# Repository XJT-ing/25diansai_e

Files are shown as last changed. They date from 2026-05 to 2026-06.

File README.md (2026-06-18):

# 2025 National Undergraduate Electronics Design Contest - Problem E

This repository contains the source code, schematics, 3D models, system block diagram, and project report for our 2025 National Undergraduate Electronics Design Contest Problem E project.

Award: National Second Prize

## Project Overview

This project implements a simple automatic aiming device based on machine vision, embedded control, motor actuation, and closed-loop correction.

## Repository Structure

- `源码/`: source code for MaixCam Pro and microcontroller control
- `原理图/`: circuit schematics
- `3D建模/`: 3D models and mechanical structure files
- `总体框图.png`: overall system block diagram
- `报告.pdf`: project report

## Note

This repository is intended for learning, communication, and project demonstration only.

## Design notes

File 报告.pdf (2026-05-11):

装订 | 装订 | 装订

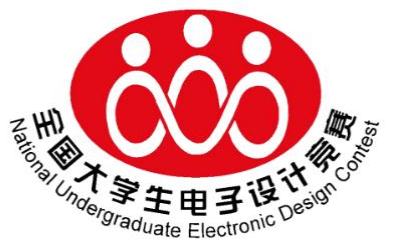
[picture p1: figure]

# 2025年全国大学生电子设计竞赛

## 简易自行瞄准装置（E题）

3cm | 参赛队代码：

装订 | 装订 | 装订

3cm

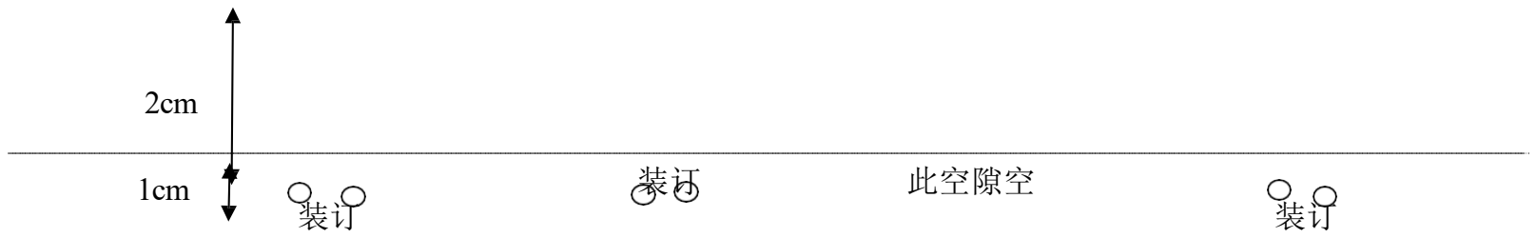
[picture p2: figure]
此空隙空

## 简易自行瞄准装置

摘要

本设计实现了集机械控制运动系统与视觉识别系统为一体的简易自行瞄准装

置。机械控制运动系统包含两部分：以 TI MSPM0G3507 为主控的自动循迹小车系

统，可按指令在规定时间沿正方形黑线精准循迹行驶设定圈数；以STM32F407VET6

为主控、步进电机驱动二维云台的激光瞄准模块，能依据接收数据完成打靶动作。

视觉识别系统基于 Sipeed MaixCAM Pro，可精准识别紫外感光靶面的轮廓、靶心

及红色圆圈，为瞄准模块提供实时定位。瞄准模块借助步进电机二维云台调控蓝

紫激光笔，无论小车静止或行驶，均可快速实现激光瞄准，保障光斑直径与距离

精度达标 。

关键词：简易自行瞄准装置；自动寻迹；激光瞄准；靶面视觉识别。

# 1.系统方案

## 1.1.机械运动控制系统方案选择

### 1.1.1. 主控选择

方案一：STM32F103C8T6。价格亲民、资料丰富易开发，但性能有限，串口数

量少，多任务处理易资源紧张。

方案二：TI MSPM0G3507。功耗低，运算高效，针对低功耗场景深度优化，

能稳定支撑自动循迹小车的基础控制需求 。

方案三：STM32F407VET6。运算性能强，具备丰富外设接口（如多路串口等），

能高效处理激光瞄准控制中的多信息交互，开发生态成熟，易于调试。

方案选择：本系统由自动循迹小车（需稳定运算主控）与激光瞄准模块（需

高性能及电机控制）构成。TIMSPM0G3507契合小车基础控制需求；STM32F407VET6

凭借高性能与丰富外设，满足瞄准模块多信息处理、精准控制要求。二者协同，

保障小车稳定、瞄准模块高效，故选用TI MSPM0G3507作为自动循迹小车主控，

STM32F407VET6作为激光瞄准模块主控 。

## 1.1.2. 机械运动部分选择

方案一：四轮四驱循迹小车，搭配舵机搭建二维云台。四驱动虽能提供较强

动力，但对于沿正方形轨迹寻迹场景，双驱动已可满足行驶需求。且四驱可能导

致转弯打滑，影响行驶稳定性；舵机虽响应较快，但在二维云台角度的精准控制，

较难满足精度要求。

方案二：四轮双驱循迹小车，搭配步进电机搭建二维云台。双驱设计简化驱

动结构，降低能耗与控制难度，更适配循迹场景的动力需求，能稳定沿黑色边线

行驶，确保小车投影不脱离轨迹；步进电机具备高精度角度控制能力，可精准驱

动二维云台调整蓝紫激光笔方向，满足静止或行驶时激光瞄准的精度要求，契合

靶面光斑直径及距离精度的指标。

方案选择：方案一存在结构冗余，易影响行驶稳定性与瞄准精度；方案二的

双驱设计适配循迹需求，步进电机驱动的云台能保障激光瞄准精度，符合装置核

心要求，故选择方案二作为系统的机械运动控制系统。

## 1.2.视觉识别系统方案选择

方案一：K210 视觉模块。主芯片为 K210，采用双核 64 位 RISC - V 架构，

算力达 1TOPS，集成 KPU 等硬件加速器，能实现靶面轮廓、靶心等基础特征识别。

不过在复杂光照或靶面有轻微形变等情况下，识别精度会受到影响，且算力拓展

空间相对有限。

方案 二 ： MaixCAM Pro 。 配 备 高 性 能 处 理 器 ， 拥 有 1GHz RISC - V

(C906)+700MHz RISC - V 的强劲 CPU 组合，搭配 256MB DDR3 内存，NPU 算力

出色，支持高分辨率图像采集，可精准识别靶面细微特征，如窄线宽的红色圆圈、

极小的靶心等 。开发环境资源丰富。

方案选择：K210 在复杂场景下的识别精度和算力方面存在局限，难以满足

本装置对靶面高精度识别的要求。而 MaixCAM Pro 凭借强大的性能、精准的识

别能力以及丰富的开发环境资源，更契合简易自行瞄准装置中视觉识别系统的核

心需求，因此选用方案二作为视觉识别系统。

## 1.3 总体方案描述

系统主要包括机械运动控制系统和视觉识别系统。其中，机械运动控制系统：

小车由TI MSPM0G3507和四轮双驱的循迹小车结构组成，激光瞄准模块由

STM32F407VET6和步进电机二维云台结构组成；视觉识别系统由MaixCAM Pro组成。

总体框如图 1-1 所示。

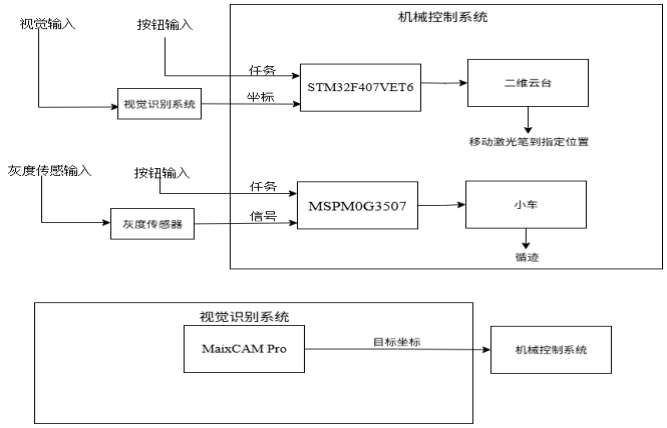
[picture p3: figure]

图 1-1 系统总体框图

# 2.理论分析与计算

## 2.1系统控制逻辑与核心算法

简易自行瞄准装置通过自动寻迹控制与瞄准调节控制协同工作，核心算法包

括灰度传感器寻迹算法、PID 控制算法及坐标映射算法。

自动寻迹小车以 TI MSPM0 系列 MCU 为控制核心，通过 8 路灰度传感器采集

轨迹信息，将传感器数据与预设黑白阈值对比，生成数字信号判断小车相对于黑

色轨迹的位置偏移1。基于偏移量，采用 PID 算法实时调节左右电机转速，实现

沿 100cm×100cm 正方形轨迹的逆时针自动寻迹，确保行驶圈数（1-5 圈）和时

间（≤20s）符合要求。

瞄准模块依托二维云台控制激光笔，采用坐标映射算法将靶面光斑与靶心的

偏差转换为云台角度调节量，结合 PID 算法实现快速瞄准：静态状态下 2s 内、

指定位置 4s 内使光斑距靶心≤2cm。

## 2.2代码实现思路

1.小车控制代码：初始化灰度传感器、电机及 PID 控制器后，进入循环采集

传感器数据，通过数字信号判断轨迹位置。利用编码器记录行驶距离，结合预设

圈数阈值触发停止逻辑，同时通过 OLED 显示行驶参数，确保行驶过程中投影不

脱离轨迹。

2.瞄准模块代码：通过串口接收靶面偏差数据，经校验后转换为目标角度。

初始化 x、y 轴 PID 控制器，根据偏差计算输出量，驱动二维云台调整激光方向。

在发挥部分，通过关联小车行驶距离与圆弧坐标，实现小车行驶 1 圈时激光沿

6cm 半径圆弧同步画圆，保证同步误差 < 1/4 圈。

3.协同控制：MSPM0 控制器与瞄准模块通过独立电源开关控制，行驶与瞄准过

程中，前者负责轨迹跟踪，后者根据位置动态调节激光方向，在发挥部分实现行

驶与瞄准的连续协同。

# 3.电路与程序设计

## 3.1 电路设计

本系统主要的电路设计分为为稳压电路部分、电机控制部分、以及系统底板

部分。

## 3.1.1 稳压电路部分

基于 RT8289GSP 芯片构建 5V 电源电路，搭配滤波、过温保护等元件；通过

RT9013 - 33GB 实现 5V 转 3.3V ，满足系统供电需求，电路如图所示。稳压电

路如图 3-1。

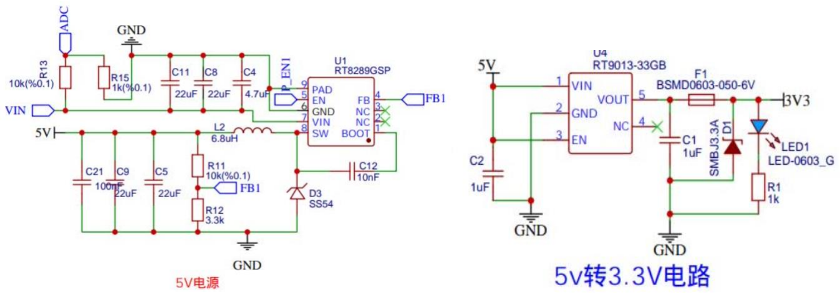
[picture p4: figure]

图 3-1 稳压电路

## 3.1.2 电机控制部分

为了驱动二维云台且满足较高的精度要求。我们使用了 2 台 42 步进电机及

其配套的驱动板。我们将三台电机的驱动排线接在电机转接板上，转接板上，两

个电机使用串口与主控f4进行通信。同时，主控TI MSPM0G3507利用TB6612FNG驱

动模块驱动小车电机。电机控制电路如图 3-2所示。

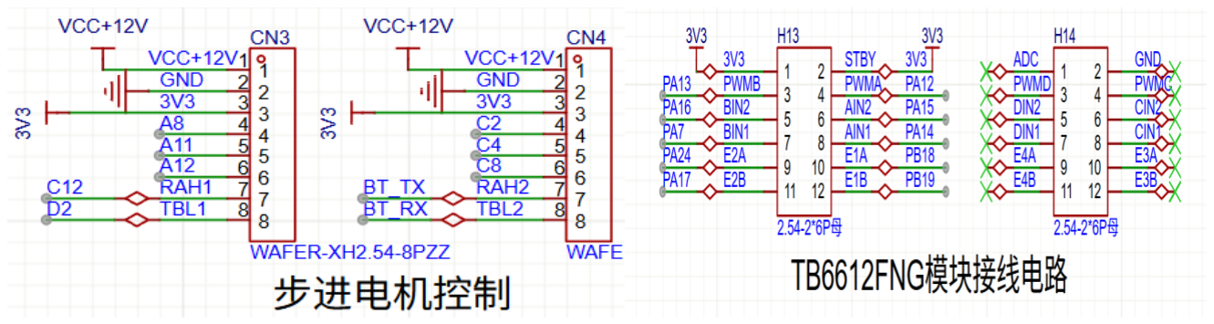
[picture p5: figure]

图 3-2 电机控制电路

## 3.1.3 系统底板部分

对于转接使用到的 IO 口，我们设计了一块底板，能够将TI MSPM0G3507核心

板和STM32F407VET6 核心板直接插入底板，排母将核心板上面的 IO 口引脚与电

机和电源连接，同时还将未使用的 IO 口引出供其他外设（如LED灯、IMU等）使

用。底板的原理图如图3-3所示。

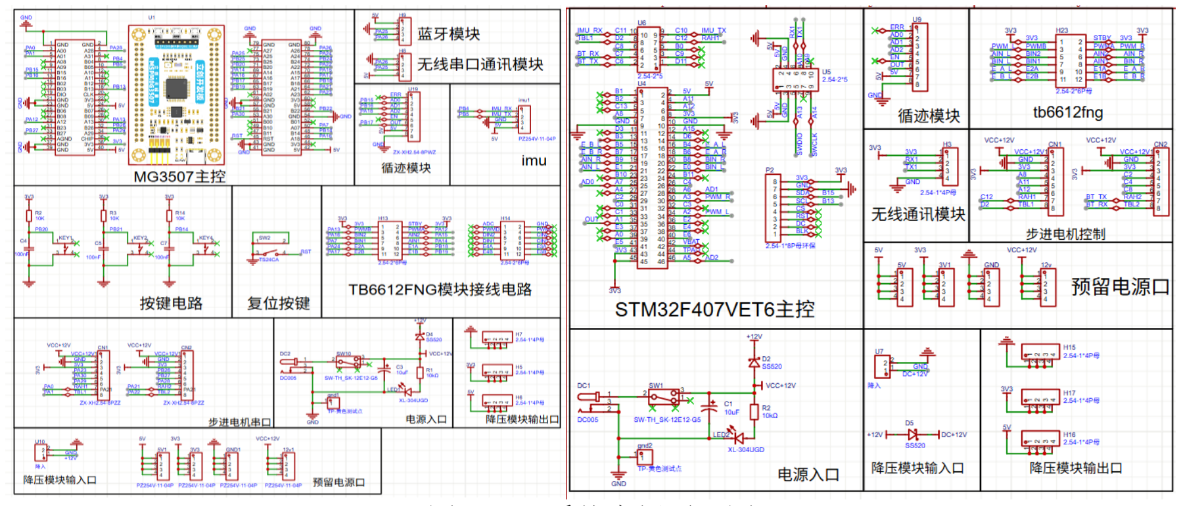
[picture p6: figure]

图 3-3 系统底板原理图

## 3.1 程序设计

本系统的程序设计主要分为机械运动控制系统部分和视觉识别系统部分。

## 3.1.1 机械运动控制系统：

本系统由TI MSPM0G3507和STM32F407VET6为主控，以 TI MSPM0G3507 为主控，

通过 TB6612FNG 输出 PWM 波控制小车电机，实现电机调速与转向控制。以

STM32F407VET6 为主控，使用串口对两个 42 步进电机进行控制，驱动支持串口

指令配置速度及转动距离。同时，系统通过按钮或者根据视觉控制系统所给的信

号对不同任务做出不同指令。

## 3.1.2 视觉识别系统

本设计以MaixCAM Pro为视觉识别系统的主控，进一步识别目标，加入IMU辅助

PID控制，将目标点与激光点差值通过串口发送到电机控制系统，使激光笔能够在

uav纸上打出想要的点和轨迹。

# 4.测试方案与测试结果

## 4.1.测试方案 4.1.1 地图及靶标的设计

地图设计：为满足小车自动寻迹需求，采用白色哑光喷绘布制作行驶场地，

水平铺于平地。按要求绘制 100cm×100cm 的正方形行驶轨迹，边线为黑色，线

宽控制在 1.8cm±0.2cm，与题目要求一致。

靶标设计：目标靶采用 A4 幅面紫外感光纸的感光面。在感光纸边缘，用

1.8cm 宽的黑色哑光胶布粘贴成长方形，勾勒出靶纸外轮廓；以靶心（直径

≤0.1cm）为圆心，用红色油性记号笔分别绘制半径为 2、4、6、8 和 10cm 的红

色圆，圆弧线宽度≤0.1cm，符合题目对靶面标记的要求，便于视觉识别系统定位

靶心及各圆弧位置。同时，靶标竖立在距离 AB 线段外 50cm 处，靶面与 AB 保

持平行，高度≤50cm，周围无强光干扰，保证激光照射后能清晰留下感光痕迹。

## 4.2 测试结果完整性

要求项 | 要求说明 | 完成情况 | 是否 达标
完成基本 要求（1） | 沿轨迹行驶，圈 数可设且限时。 | 行驶圈数 N 可在 1-5 之间设定，行驶时间 t≤20s | 是
完成基本 要求（2） | 自定位置 2s 内 瞄准靶心。 | 2s内完成且距离靶心小于2cm | 是
完成基本 要求（3） | 指定位置 4s 内 瞄准靶心。 | 4s内完成且距离靶心小于2cm | 是
完成发挥 部分（1） | 1 圈行驶，20s 内瞄准 | 绝大部分时间完成 | 基本 达标
完成发挥 部分（2） | 2 圈行驶，40s 内瞄准 | 50%概率完成 | 基本 合格

## 4.3 测试结果分析

本系统能良好完成部分要求，但测试次数较少，可能存在不稳定性，还存在

改进空间。

## 4.4 总结展望

本次设计旨在开发一种简易自行瞄准装置，使大家能够感受到机械运动控制

和视觉识别的魅力。在这此项目的制作中，我们团队学到了很多。首先，我们学

到了如何进行系统化的需求分析和设计规划。其次，我们学到了如何进行合理的

电路设计以及系统方案的选择。此外，我们团队还学到了团队合作和项目管理的

重要性。最终，我们的作品虽然与预期水平有差距，但已经是我们全力以赴，共

同协作努力的结果。

要求项 | 要求说明 | 完成情况 | 是否 达标
完成发挥 部分（3） | 1 圈行驶，同步 画指定圆 | 未完成 | 否
完成发挥 部分（其 他） | 其他创新性表现 | 可现场学习人脸并在识别人脸时 关闭激光笔保护人眼 | 是

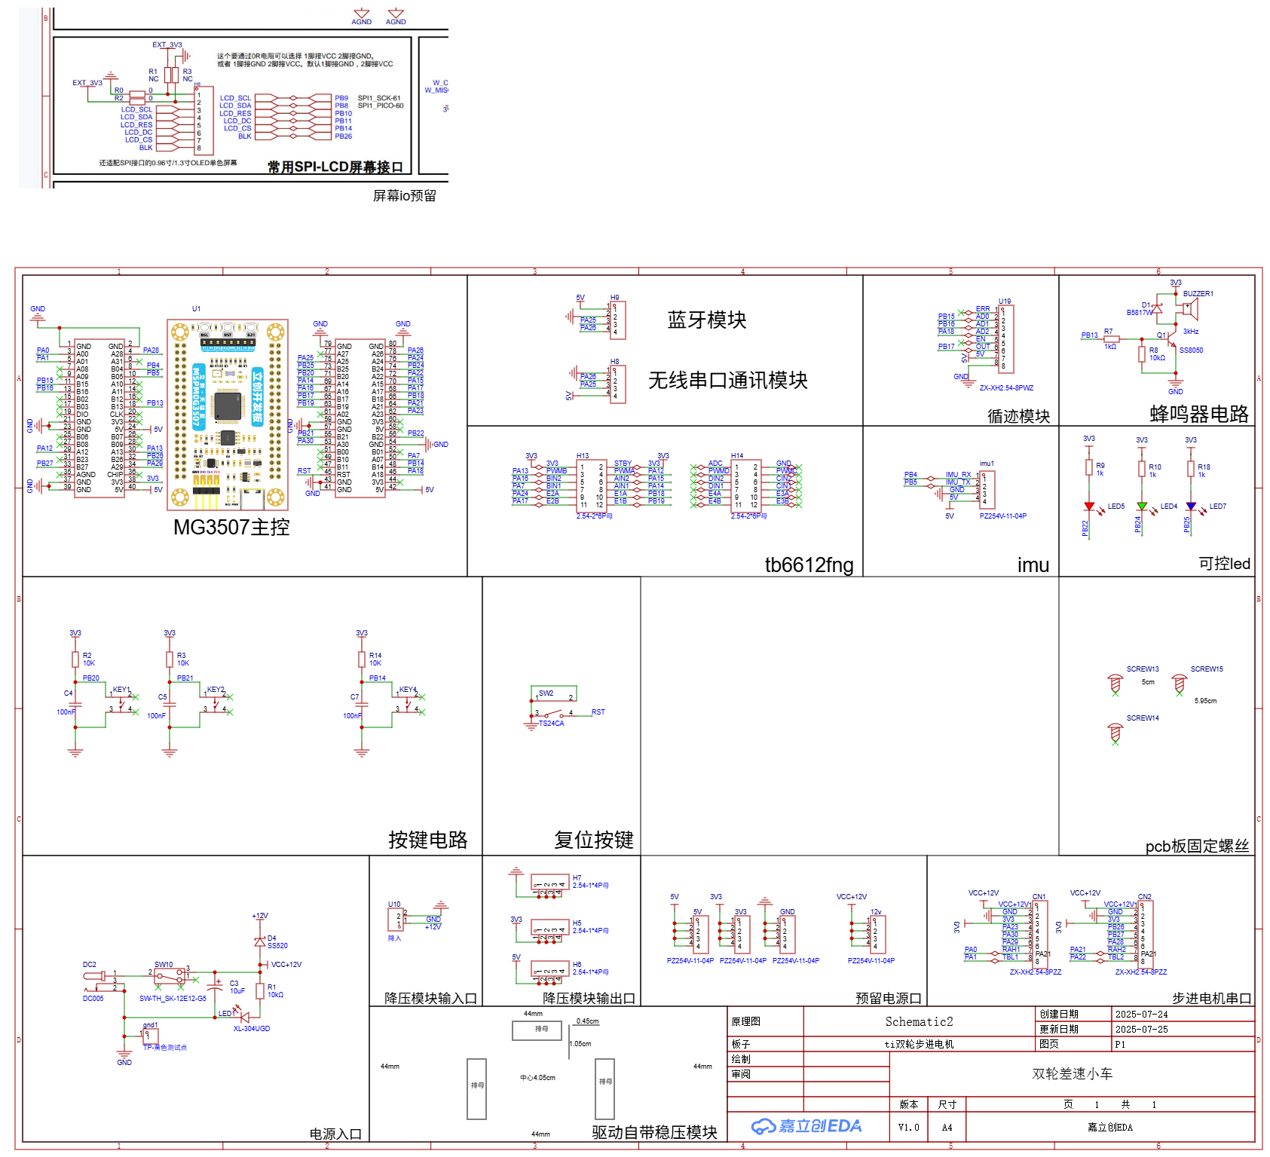
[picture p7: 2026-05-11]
原理图/SCH_Schematic2_1-P1_2025-08-01.png

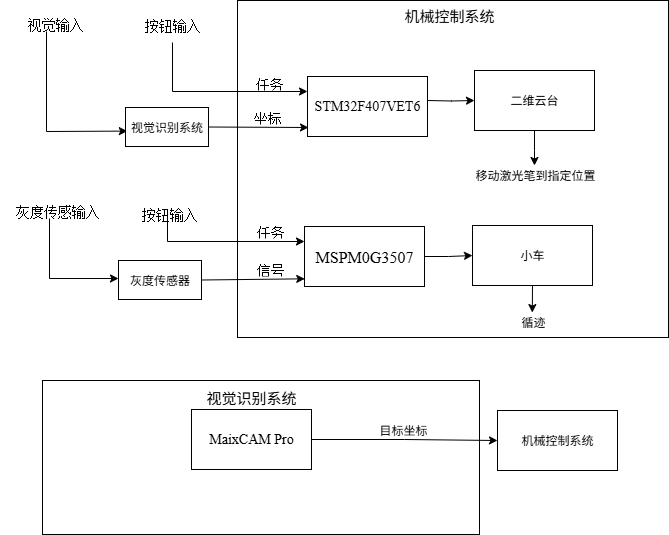
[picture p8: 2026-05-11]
总体框图.png

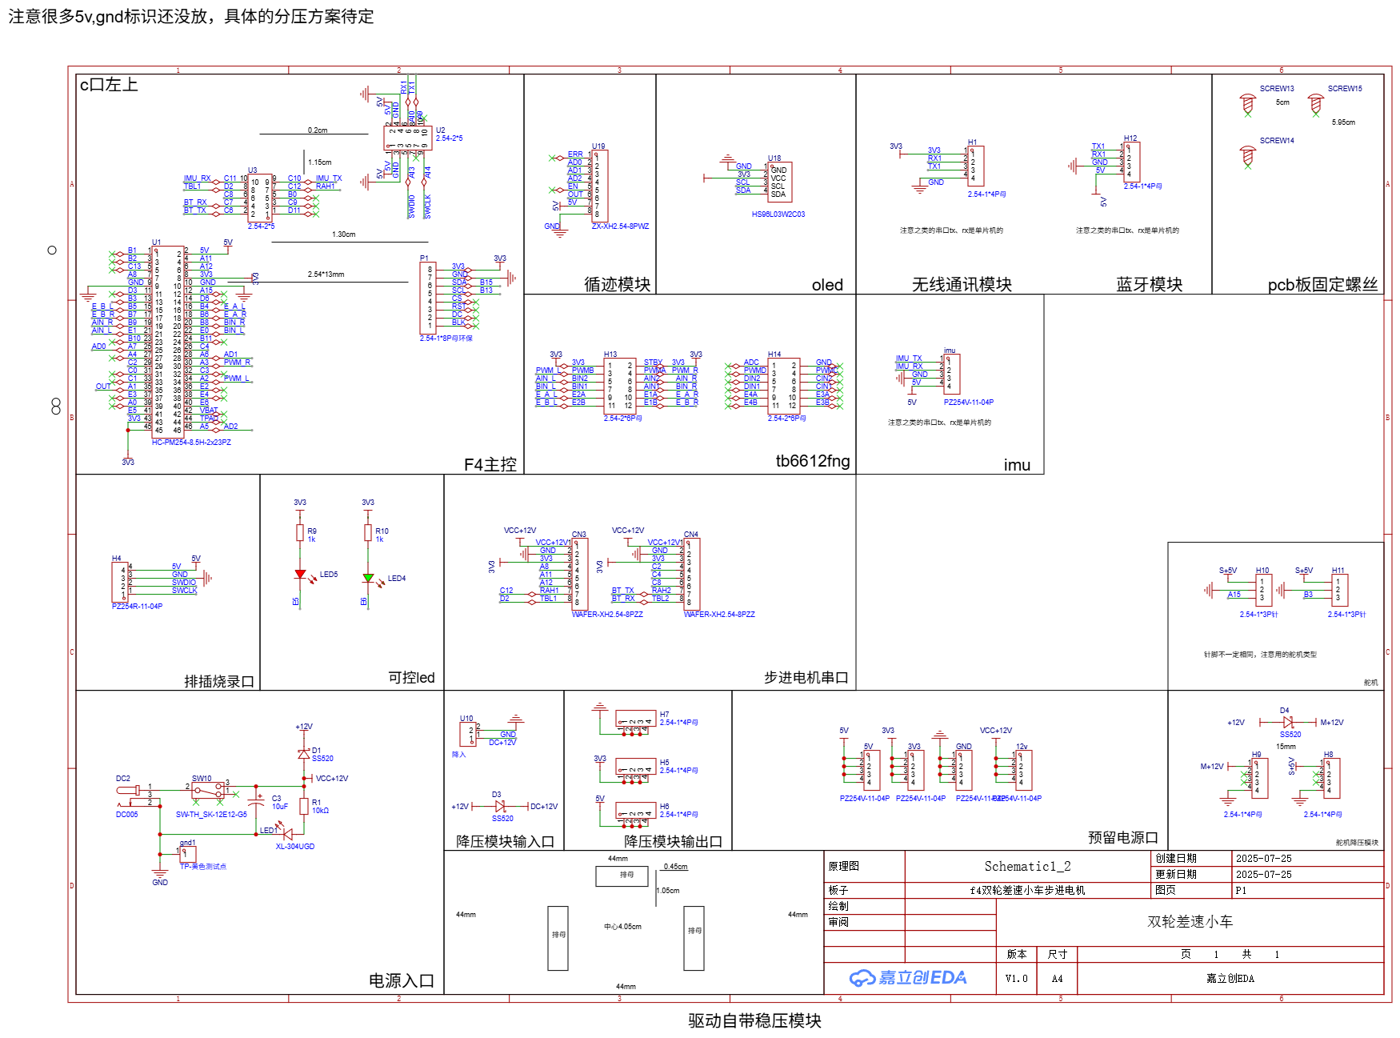
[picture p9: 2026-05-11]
原理图/f4控制板.png

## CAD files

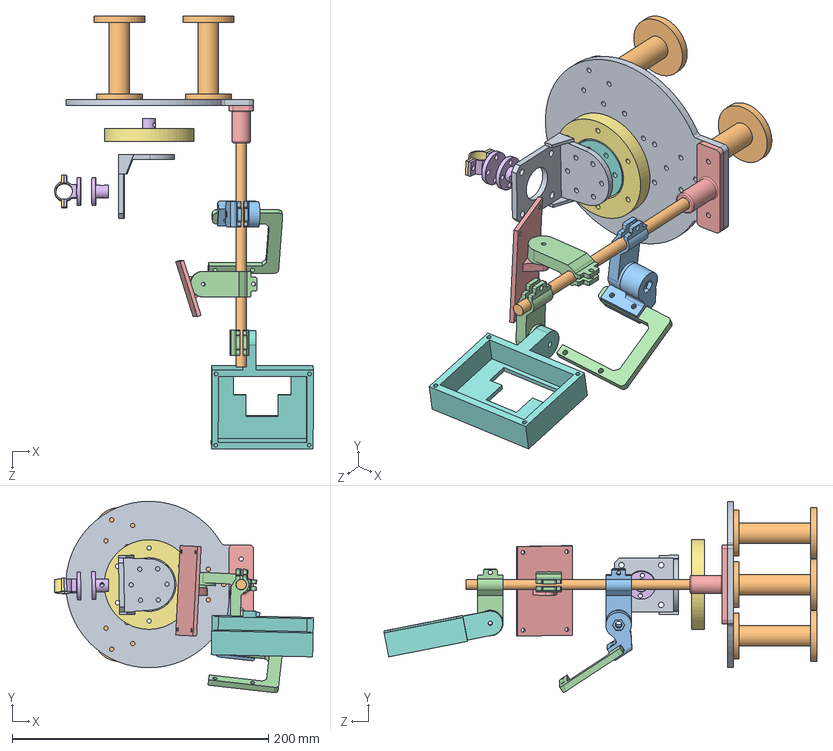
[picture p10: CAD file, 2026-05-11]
3D建模/云台总文件/云台总文件/云台装配图（不用管）.SLDASM
202.3 x 149.5 x 338.2 mm
示意图2（不用管）

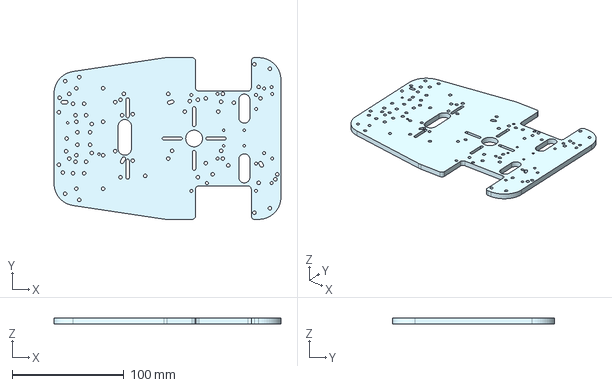
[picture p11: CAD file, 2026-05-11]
3D建模/_pcs_.appdata/ent/sharedir/2385190363/4.非ROS产品附送资料/2.套件类资料/WHEELTEC R1.R3.R3X.TT马达系列底盘客户资料/R1.R3.R3X.TT马达系列底盘客户资料_2023.10.7/1.安装视频、三维模型与2D图纸/R3X底盘/R3X三轮两驱/R3X三轮两驱三维模型/R3X四驱差速板件.stp
203.5 x 145.0 x 5.00 mm

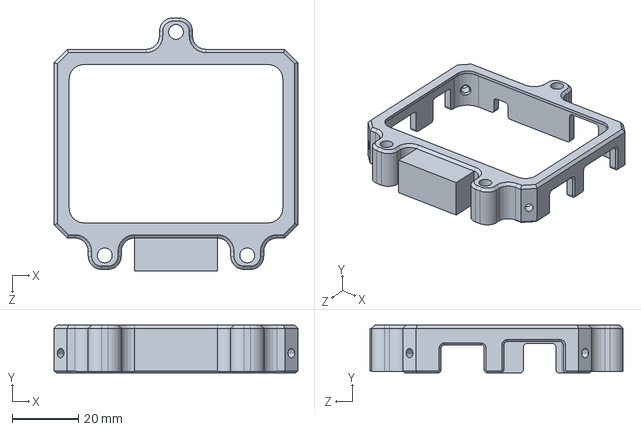
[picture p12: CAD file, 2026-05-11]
3D建模/MaixCam Pro 扩展外壳.step.SLDPRT
73.8 x 14.5 x 76.6 mm

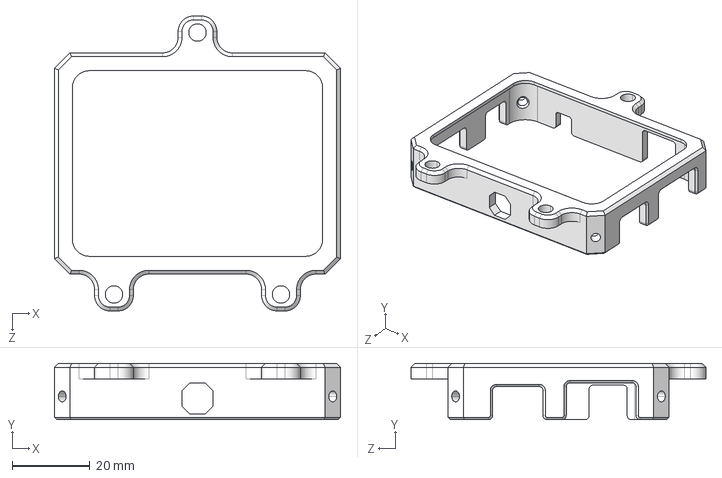
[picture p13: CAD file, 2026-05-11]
3D建模/MaixCam+Pro+扩展外壳/MaixCam Pro 扩展外壳.step
73.8 x 14.5 x 76.1 mm

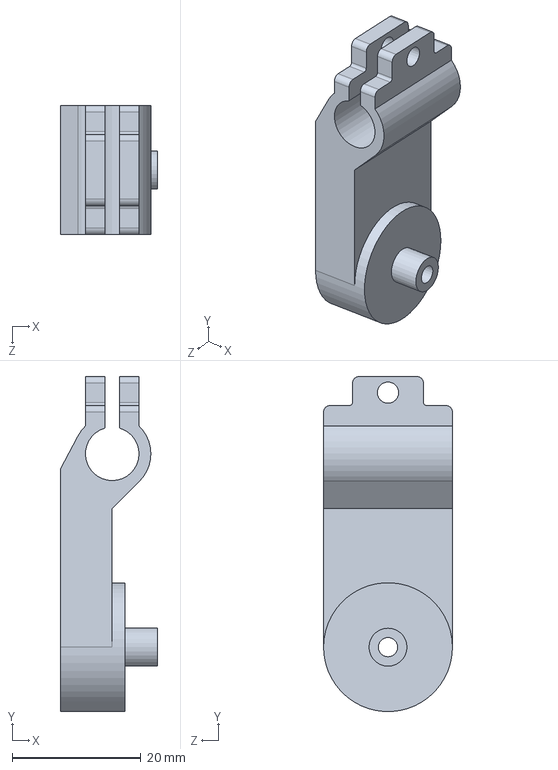
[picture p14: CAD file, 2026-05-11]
3D建模/云台总文件/云台总文件/9.SLDPRT
15.0 x 52.0 x 20.0 mm

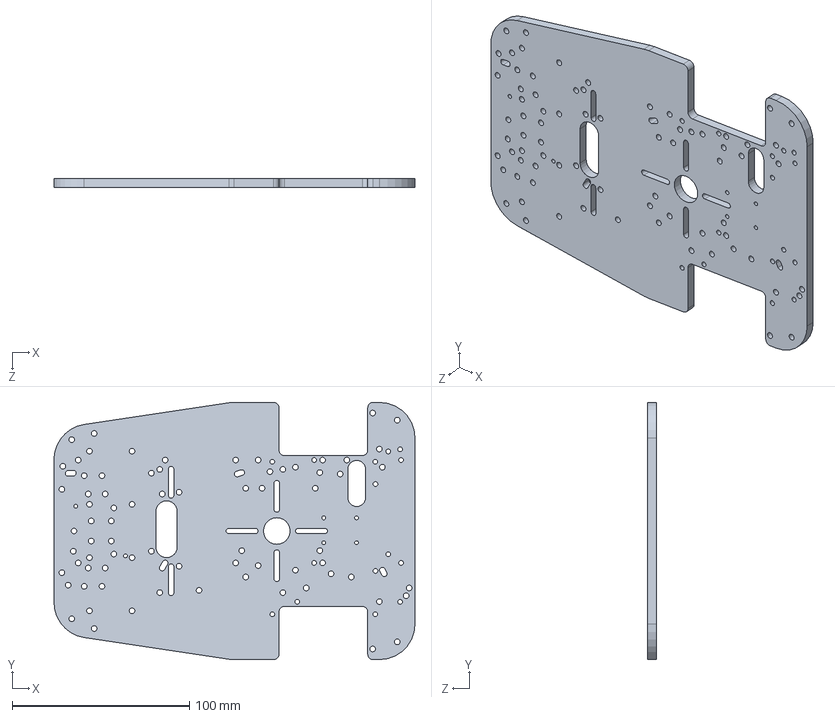
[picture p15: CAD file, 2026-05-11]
3D建模/小车底盘改/底板改.SLDPRT
203.5 x 145.0 x 5.00 mm

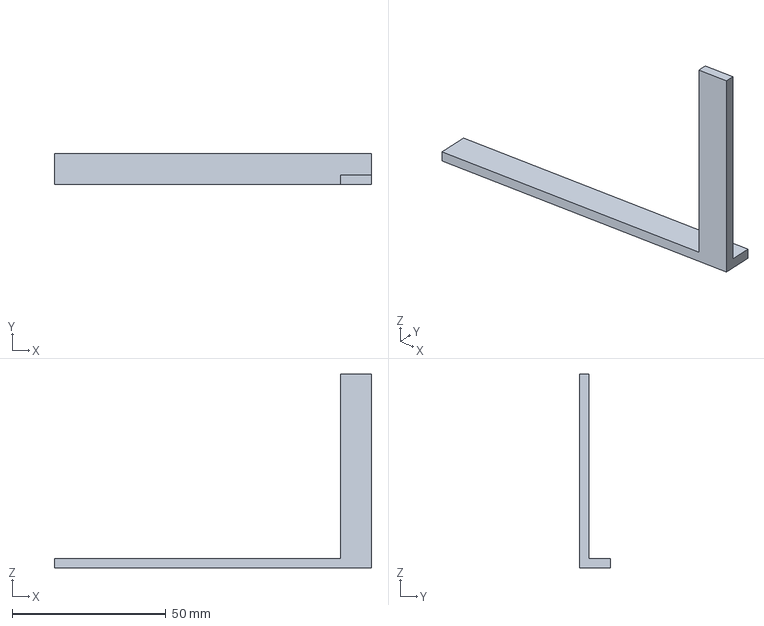
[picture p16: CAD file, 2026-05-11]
3D建模/排线支架/零件1g.3mf
103.0 x 10.0 x 63.0 mm

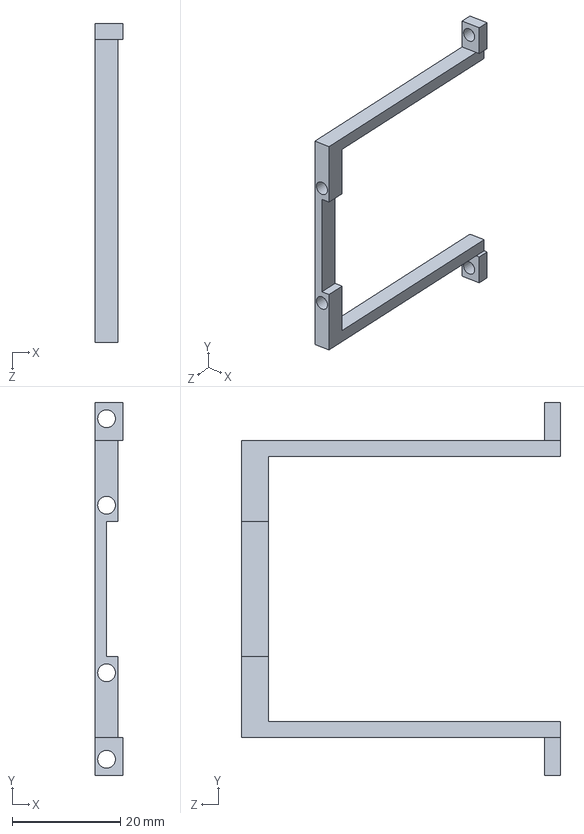
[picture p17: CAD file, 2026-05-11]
3D建模/步进电机云台/步进电机云台/固定1.SLDPRT
5.10 x 69.0 x 59.0 mm

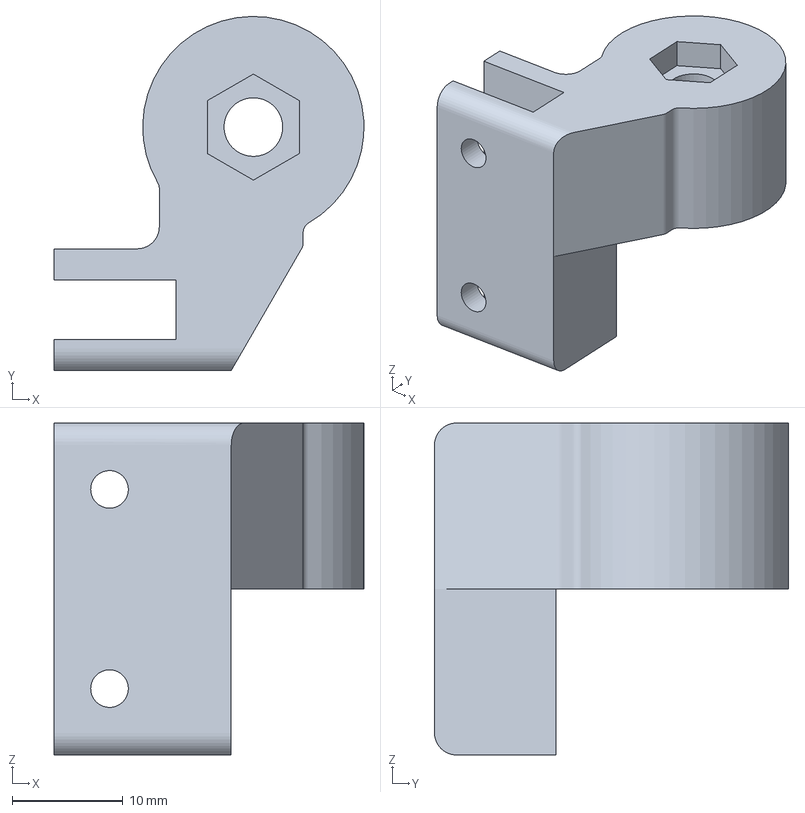
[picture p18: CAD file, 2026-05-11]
3D建模/步进电机做二维云台/10.3MF
28.0 x 32.0 x 30.0 mm

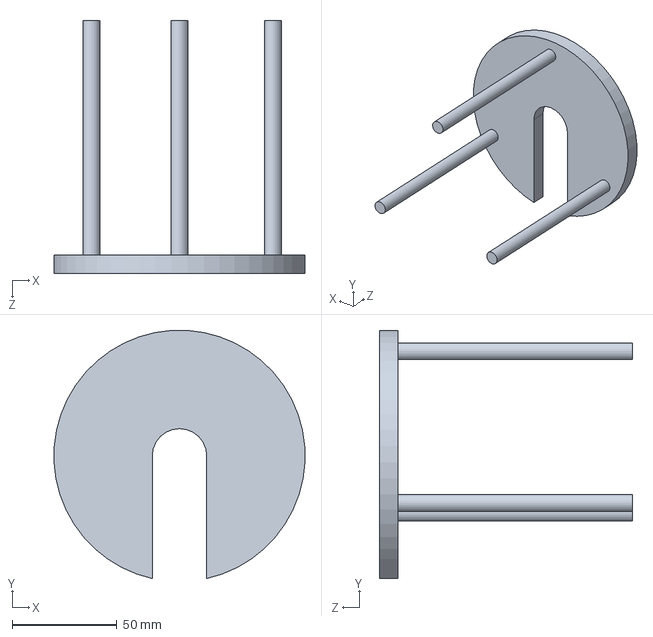
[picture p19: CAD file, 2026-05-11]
3D建模/相机支架/云台支架.SLDPRT
119.8 x 118.4 x 121.0 mm

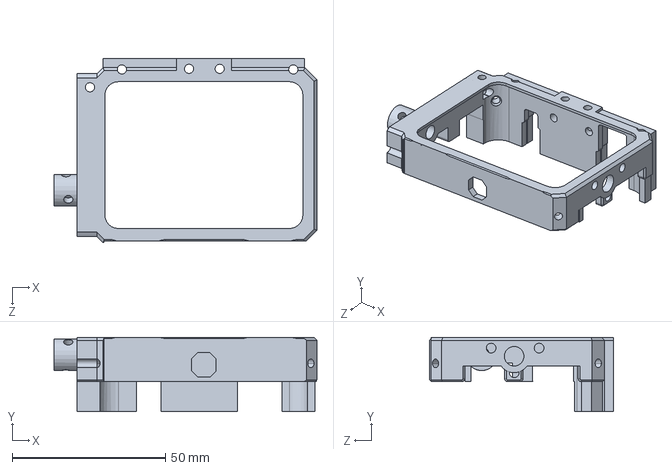
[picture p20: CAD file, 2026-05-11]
3D建模/相机框自画/5ggg带激光笔外壳.SLDPRT
85.8 x 24.3 x 60.1 mm

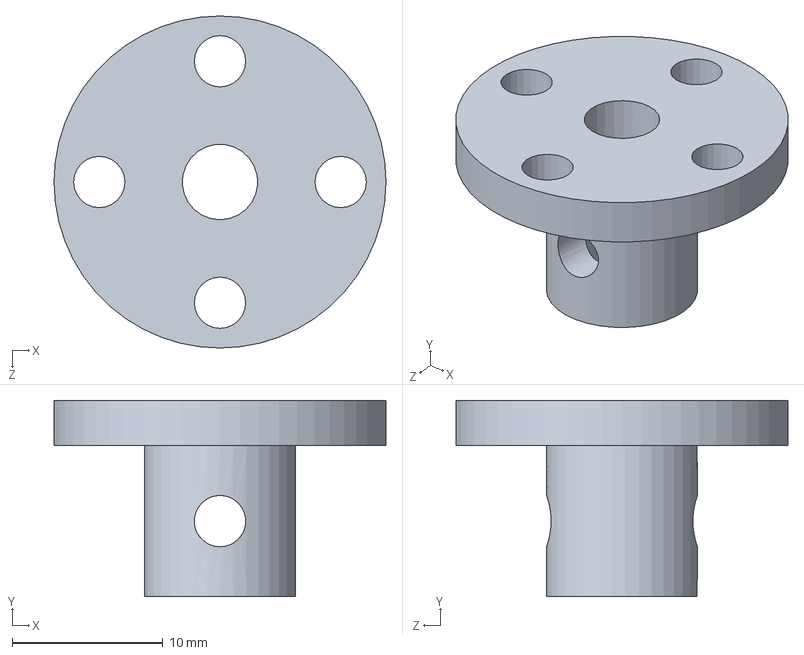
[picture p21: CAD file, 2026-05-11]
3D建模/云台总文件/云台总文件/4.SLDPRT
22.0 x 13.0 x 22.0 mm

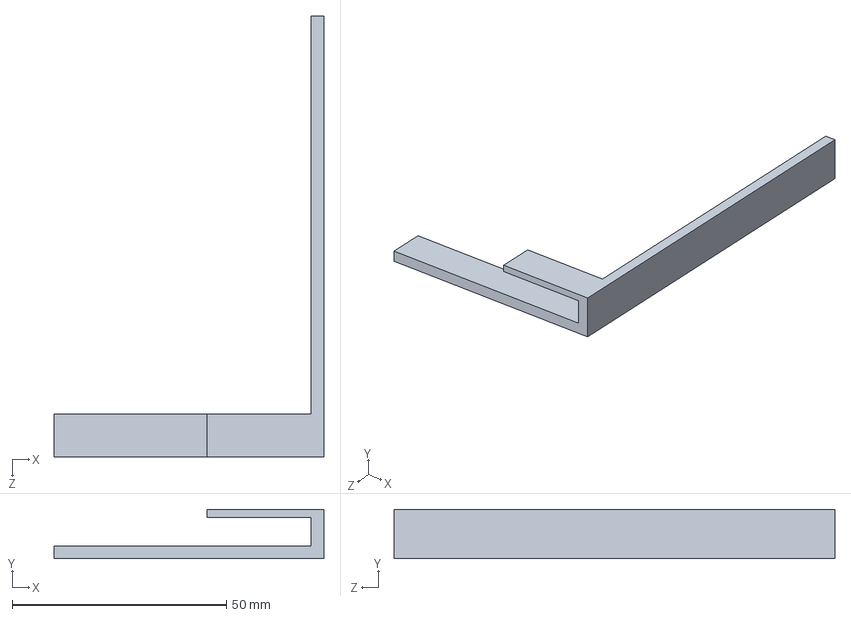
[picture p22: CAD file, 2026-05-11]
3D建模/排线支架/零件12.SLDPRT
63.0 x 11.5 x 103.0 mm

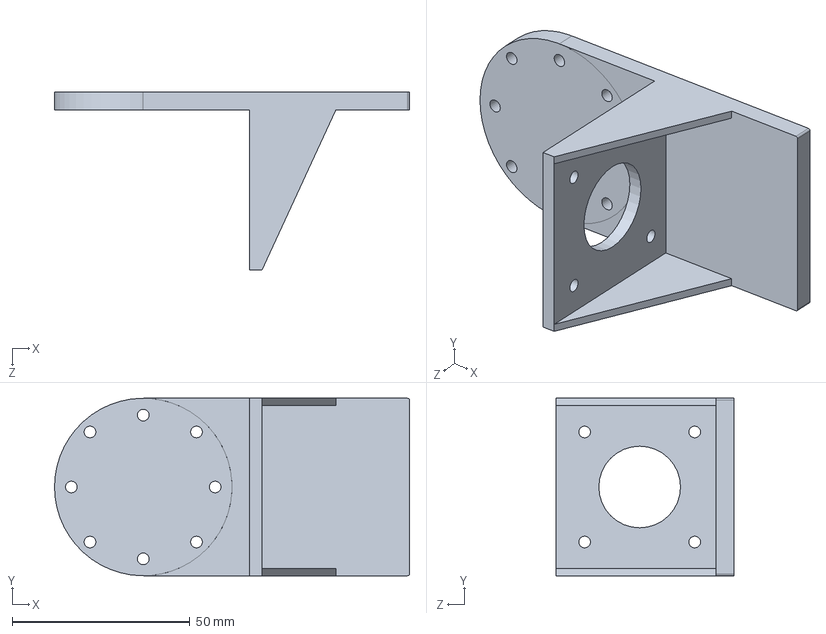
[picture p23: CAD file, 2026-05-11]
3D建模/步进电机云台/步进电机云台/Y轴.SLDPRT
100.0 x 50.0 x 50.0 mm

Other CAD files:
3D建模/小车底盘改/R3X四驱差速板件.stp.SLDPRT
3D建模/步进电机做二维云台/9.3MF
3D建模/CCD支架客户图20250611.step
3D建模/云台总文件/云台总文件/1 (1).SLDPRT
3D建模/云台总文件/云台总文件/1.SLDPRT
3D建模/云台总文件/云台总文件/10.SLDPRT
3D建模/云台总文件/云台总文件/11.SLDPRT
3D建模/云台总文件/云台总文件/14.SLDPRT
3D建模/云台总文件/云台总文件/15.SLDPRT
3D建模/云台总文件/云台总文件/2.SLDPRT
3D建模/云台总文件/云台总文件/3.SLDPRT
3D建模/云台总文件/云台总文件/5.SLDPRT
3D建模/云台总文件/云台总文件/6.SLDPRT
3D建模/云台总文件/云台总文件/7.SLDPRT
3D建模/云台总文件/云台总文件/8.SLDPRT
3D建模/云台总文件/云台总文件/9(2).SLDPRT
3D建模/云台总文件/云台总文件/摄像头支架.STL
3D建模/云台总文件/云台总文件/摄像头支柱.STL
3D建模/云台总文件/云台总文件/摄像头盖子.STL
3D建模/云台总文件/云台总文件/摄像头连接件.3mf
3D建模/云台总文件/云台总文件/摄像头连接件.STL
3D建模/云台总文件/云台总文件/示意图2（不用管）.SLDPRT
3D建模/云台总文件/云台总文件/示意图（不用管）.SLDPRT
3D建模/小车底盘改/底板改.3mf
3D建模/排线支架/零件1.3mf
3D建模/排线支架/零件1.SLDPRT
3D建模/排线支架/零件12.3mf
3D建模/排线支架/零件122.3mf
3D建模/排线支架/零件123.3mf
3D建模/排线支架/零件131.3mf
3D建模/排线支架/零件131.SLDPRT
3D建模/步进电机云台/步进电机云台/底座.SLDPRT
3D建模/步进电机云台/步进电机云台/连轴器.SLDPRT
3D建模/步进电机做二维云台/11.3MF
3D建模/步进电机做二维云台/14.3mf
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

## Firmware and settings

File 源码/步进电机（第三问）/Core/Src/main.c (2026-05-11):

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
/* Includes ------------------------------------------------------------------*/
#include "main.h"
#include "usart.h"
#include "gpio.h"

/* USER CODE BEGIN Includes */
#include "Emm_V5.h"
#include <stdbool.h>
#include "key.h"
#include <pid.h>
/* USER CODE END Includes */


/* USER CODE BEGIN PV */
unsigned char rx_buff[256]={0};

/* USER CODE END PV */

void SystemClock_Config(void);
/* USER CODE BEGIN 0 */
	uint8_t response[32];//character strings for serial port and led
	uint8_t Urxbuf[9];
	int Usart_Compelet;
	int myabs(int a)
{ 		   
	  int temp;
		if(a<0)  temp=-a;  
	  else temp=a;
	  return temp;
}
		int three_flag1=0;
/* USER CODE END 0 */

/**
  * @brief  The application entry point.
  * @retval int
  */
int main(void)
{

  /* MCU Configuration--------------------------------------------------------*/

  /* Reset of all peripherals, Initializes the Flash interface and the Systick. */
  HAL_Init();

  /* Configure the system clock */
  SystemClock_Config();

  /* Initialize all configured peripherals */
  MX_GPIO_Init();
  MX_USART1_UART_Init();
  MX_USART6_UART_Init();
  MX_UART5_Init();
  /* USER CODE BEGIN 2 */

		int speed=75;
		int error = 1;
		int dir;
    uint8_t check = 0;
		int i;
    float target_angle1 = 0.0f, target_angle2 = 0.0f;
		// 创建离散 PID 控制器
    DiscretePIDController pid_x, pid_y;
    CoordinatePID coord_pid;
    float p=0.6;
		float pid_i=0.0;
		float d=0.2;
    // 初始化 PID 参数（与原始Python代码相同）
    PID_Init(&pid_x, p, pid_i, d, -400.0, 400.0);
    PID_Init(&pid_y, p, pid_i, d, -400.0, 400.0);
    
    coord_pid.x = &pid_x;
    coord_pid.y = &pid_y;
		
		 double output[2];       // 输出结果
  /* USER CODE END 2 */

  /* Infinite loop */
  /* USER CODE BEGIN WHILE */
  while (1)
  {
    /* USER CODE END WHILE */

    /* USER CODE BEGIN 3 */
		Key_Scan();
    error=1;
		check = 0;
		target_angle1 = 0.0f, target_angle2 = 0.0f;
    if(Usart_Compelet == 1) // 串口通信完成
    {
        // 计算校验（前8字节异或）
        for( i = 0; i < 8; i++)
        {
            check ^= Urxbuf[i]; // 异或校验
        }
        
        // 检查校验结果（第9字节是校验位）
        if(check == Urxbuf[8]) 
        {
            error = 0; // 校验成功
            
            // 将接收到的字节转换为浮点数
            memcpy(&target_angle1, &Urxbuf[0], 4);  // 前4字节是第一个浮点数
            memcpy(&target_angle2, &Urxbuf[4], 4);  // 后4字节是第二个浮点数
        }
        else 
        {
            error = 1; // 校验失败
        }
        
        Usart_Compelet = 0; // 重置完成标志
    }	

    if(error == 0) // 数据有效
    {       
        // 坐标制转换示例（如果需要）
        coordinate_pid(target_angle1, target_angle2, &coord_pid, output);
        if(output[0] != 0.0f) 
        {
            // x坐标换算成角度 500mm 32*8=256
						
            int angle1 = output[0];
						dir=(angle1>0)?1:0;
						Emm_V5_Pos_Control(0, dir, speed, 0, myabs(angle1), 0, 0, huart5);
        }
        if(output[1] != 0.0f) 
        {
            // y坐标换算成角度
            int angle2 = output[1];
						dir=(angle2>0)?1:0;
            Emm_V5_Pos_Control(0, dir, speed, 0, myabs(angle2), 0, 0, huart6);
        }
        HAL_GPIO_WritePin(LED_GREEN_GPIO_Port,LED_GREEN_Pin,GPIO_PIN_SET);		
    }
  }
  /* USER CODE END 3 */
}

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


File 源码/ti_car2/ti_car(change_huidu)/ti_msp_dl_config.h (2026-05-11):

/*
 * Copyright (c) 2023, Texas Instruments Incorporated - http://www.ti.com
 * All rights reserved.
 *
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
 * *  Redistributions of source code must retain the above copyright
 *    notice, this list of conditions and the following disclaimer.
 *
 * *  Redistributions in binary form must reproduce the above copyright
 *    notice, this list of conditions and the following disclaimer in the
 *    documentation and/or other materials provided with the distribution.
 *
 * *  Neither the name of Texas Instruments Incorporated nor the names of
 *    its contributors may be used to endorse or promote products derived
 *    from this software without specific prior written permission.
 *
 * THIS SOFTWARE IS PROVIDED BY THE COPYRIGHT HOLDERS AND CONTRIBUTORS "AS IS"
 * AND ANY EXPRESS OR IMPLIED WARRANTIES, INCLUDING, BUT NOT LIMITED TO,
 * THE IMPLIED WARRANTIES OF MERCHANTABILITY AND FITNESS FOR A PARTICULAR
 * PURPOSE ARE DISCLAIMED. IN NO EVENT SHALL THE COPYRIGHT OWNER OR
 * CONTRIBUTORS BE LIABLE FOR ANY DIRECT, INDIRECT, INCIDENTAL, SPECIAL,
 * EXEMPLARY, OR CONSEQUENTIAL DAMAGES (INCLUDING, BUT NOT LIMITED TO,
 * PROCUREMENT OF SUBSTITUTE GOODS OR SERVICES; LOSS OF USE, DATA, OR PROFITS;
 * OR BUSINESS INTERRUPTION) HOWEVER CAUSED AND ON ANY THEORY OF LIABILITY,
 * WHETHER IN CONTRACT, STRICT LIABILITY, OR TORT (INCLUDING NEGLIGENCE OR
 * OTHERWISE) ARISING IN ANY WAY OUT OF THE USE OF THIS SOFTWARE,
 * EVEN IF ADVISED OF THE POSSIBILITY OF SUCH DAMAGE.
 */

/*
 *  ============ ti_msp_dl_config.h =============
 *  Configured MSPM0 DriverLib module declarations
 *
 *  DO NOT EDIT - This file is generated for the MSPM0G350X
 *  by the SysConfig tool.
 */
#ifndef ti_msp_dl_config_h
#define ti_msp_dl_config_h

#define CONFIG_MSPM0G350X
#define CONFIG_MSPM0G3507

#if defined(__ti_version__) || defined(__TI_COMPILER_VERSION__)
#define SYSCONFIG_WEAK __attribute__((weak))
#elif defined(__IAR_SYSTEMS_ICC__)
#define SYSCONFIG_WEAK __weak
#elif defined(__GNUC__)
#define SYSCONFIG_WEAK __attribute__((weak))
#endif

#include <ti/devices/msp/msp.h>
#include <ti/driverlib/driverlib.h>
#include <ti/driverlib/m0p/dl_core.h>

#ifdef __cplusplus
extern "C" {
#endif

/*
 *  ======== SYSCFG_DL_init ========
 *  Perform all required MSP DL initialization
 *
 *  This function should be called once at a point before any use of
 *  MSP DL.
 */


/* clang-format off */

#define POWER_STARTUP_DELAY                                                (16)


#define GPIO_HFXT_PORT                                                     GPIOA
#define GPIO_HFXIN_PIN                                             DL_GPIO_PIN_5
#define GPIO_HFXIN_IOMUX                                         (IOMUX_PINCM10)
#define GPIO_HFXOUT_PIN                                            DL_GPIO_PIN_6
#define GPIO_HFXOUT_IOMUX                                        (IOMUX_PINCM11)
#define CPUCLK_FREQ                                                     80000000



/* Defines for PWM */
#define PWM_INST                                                           TIMG0
#define PWM_INST_IRQHandler                                     TIMG0_IRQHandler
#define PWM_INST_INT_IRQN                                       (TIMG0_INT_IRQn)
#define PWM_INST_CLK_FREQ                                               40000000
/* GPIO defines for channel 0 */
#define GPIO_PWM_C0_PORT                                                   GPIOA
#define GPIO_PWM_C0_PIN                                           DL_GPIO_PIN_12
#define GPIO_PWM_C0_IOMUX                                        (IOMUX_PINCM34)
#define GPIO_PWM_C0_IOMUX_FUNC                       IOMUX_PINCM34_PF_TIMG0_CCP0
#define GPIO_PWM_C0_IDX                                      DL_TIMER_CC_0_INDEX
/* GPIO defines for channel 1 */
#define GPIO_PWM_C1_PORT                                                   GPIOA
#define GPIO_PWM_C1_PIN                                           DL_GPIO_PIN_13
#define GPIO_PWM_C1_IOMUX                                        (IOMUX_PINCM35)
#define GPIO_PWM_C1_IOMUX_FUNC                       IOMUX_PINCM35_PF_TIMG0_CCP1
#define GPIO_PWM_C1_IDX                                      DL_TIMER_CC_1_INDEX
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

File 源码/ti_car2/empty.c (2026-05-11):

/*
 * Copyright (c) 2021, Texas Instruments Incorporated
 * All rights reserved.
 *
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
 * *  Redistributions of source code must retain the above copyright
 *    notice, this list of conditions and the following disclaimer.
 *
 * *  Redistributions in binary form must reproduce the above copyright
 *    notice, this list of conditions and the following disclaimer in the
 *    documentation and/or other materials provided with the distribution.
 *
 * *  Neither the name of Texas Instruments Incorporated nor the names of
 *    its contributors may be used to endorse or promote products derived
 *    from this software without specific prior written permission.
 *
 * THIS SOFTWARE IS PROVIDED BY THE COPYRIGHT HOLDERS AND CONTRIBUTORS "AS IS"
 * AND ANY EXPRESS OR IMPLIED WARRANTIES, INCLUDING, BUT NOT LIMITED TO,
 * THE IMPLIED WARRANTIES OF MERCHANTABILITY AND FITNESS FOR A PARTICULAR
 * PURPOSE ARE DISCLAIMED. IN NO EVENT SHALL THE COPYRIGHT OWNER OR
 * CONTRIBUTORS BE LIABLE FOR ANY DIRECT, INDIRECT, INCIDENTAL, SPECIAL,
 * EXEMPLARY, OR CONSEQUENTIAL DAMAGES (INCLUDING, BUT NOT LIMITED TO,
 * PROCUREMENT OF SUBSTITUTE GOODS OR SERVICES; LOSS OF USE, DATA, OR PROFITS;
 * OR BUSINESS INTERRUPTION) HOWEVER CAUSED AND ON ANY THEORY OF LIABILITY,
 * WHETHER IN CONTRACT, STRICT LIABILITY, OR TORT (INCLUDING NEGLIGENCE OR
 * OTHERWISE) ARISING IN ANY WAY OUT OF THE USE OF THIS SOFTWARE,
 * EVEN IF ADVISED OF THE POSSIBILITY OF SUCH DAMAGE.
 */

#include "ti_msp_dl_config.h"
#include "stdint.h"
#include "OLED.h"
#include "gray_track.h"
#include "motor.h"
#include "pid.h"
#include "No_Mcu_Ganv_Grayscale_Sensor_Config.h"
#include "Encoder.h"
#include "stdint.h"
unsigned short Anolog[8]={0};
unsigned short white[8]={2932,2056,2307,2416,3011,2929,2306,2187};
unsigned short black[8]={863,267,334,585,1262,1121,728,548};
unsigned short Normal[8];
unsigned short Digtal_sign[8]={0,0,0,0,0,0,0,0};
No_MCU_Sensor sensor;
int encoder_count=0;
extern struct ENCODER  Encoder ;

bool flag1=0;
bool stopflag=0;
unsigned short times=0;

uint8_t response[32];//character strings for serial port and led
int main(void)
{
		timer_init();
		SYSCFG_DL_init();
//		No_MCU_Ganv_Sensor_Init_Frist(&sensor);
		No_MCU_Ganv_Sensor_Init(&sensor,white,black);
    
		encoder_init();
		
		pid_init(&motorA, POSITION_PID, 20, 0, 2);
		pid_init(&motorB, POSITION_PID, 20, 0, 2);
		OLED_Init();
//		sprintf((char*)response, "area:");//track
//		OLED_ShowString(1,1,(char*)response);
		sprintf((char*)response, "encoder:");//distance
		OLED_ShowString(2,1,(char*)response);
		sprintf((char*)response, "times:");//speed of left
		OLED_ShowString(3,1,(char*)response);
		sprintf((char*)response, "start:");//speed of right
		OLED_ShowString(4,1,(char*)response);
    while (1) {
			No_Mcu_Ganv_Sensor_Task_Without_tick(&sensor,Digtal_sign);//get sensor's data			
//		sprintf((char *)response,"%d%d%d%d%d%d%d%d",Digtal_sign[0],Digtal_sign[1],Digtal_sign[2],Digtal_sign[3],Digtal_sign[4],Digtal_sign[5],Digtal_sign[6],Digtal_sign[7]);
//		OLED_ShowString(1,6,(char*)response);//gray of track
		OLED_ShowSignedNum(1,1,12400*times,5);	//distance	
		OLED_ShowSignedNum(2,9,encoder_count,5);	//distance
		OLED_ShowSignedNum(3,6,times,2);	//times
		OLED_ShowSignedNum(4,7,flag1,2);	//start
			//12400 distance of one circule
    }
}

void Pid_Time_INST_IRQHandler(void){
//		No_Mcu_Ganv_Sensor_Task_Without_tick(&sensor,Digtal_sign);//get sensor's data
		if(flag1 == 1){
			motorA.now = Encoder.countl;//get speed
			motorB.now = Encoder.countr;//get speed
			pid_control();
		}
}

			bool temp;
			bool key1_flag=0;
			bool key1_temp=0;
			bool key2_flag=0;
			bool key2_temp=0;
			bool key4_flag=0;
			bool key4_temp=0;

void Key_Scan(void)
{	   
	//////////////KEY1////////开始按键			
				key1_temp=key1_flag;
				key1_flag=DL_GPIO_readPins(KEY_PORT,KEY_KEY1_PIN);//key1
			if(key1_temp==1&&key1_flag==0){
				flag1=1;
			}
//////////////KEY2////////圈数按键			
				key2_temp=key2_flag;
				key2_flag=DL_GPIO_readPins(KEY_PORT,KEY_KEY2_PIN);//key1
			if(key2_temp==1&&key2_flag==0){	
				times=(times%5+1);
				flag1=0;
			}
//////////////KEY4////////stop按键				
			key4_temp=key4_flag;
			key4_flag=DL_GPIO_readPins(KEY_PORT,KEY_KEY4_PIN);//key2
			if(key4_temp==1&&key4_flag==0){	
				flag1=0;
				encoder_count=0;
				motorA_duty(0);
				motorB_duty(0);
			}
}

void Huidu_Time_INST_IRQHandler(void){

		Key_Scan();
		if(encoder_count>=(12400*times)){
			flag1=0;
			motorA_duty(0);
			motorB_duty(0);
		}
}

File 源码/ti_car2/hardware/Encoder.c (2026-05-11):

#include "Encoder.h"


struct ENCODER  Encoder ;
extern int encoder_count;

void encoder_init(void)
{
	//编码器引脚外部中断
	NVIC_ClearPendingIRQ(EncoderA_INT_IRQN);
    NVIC_ClearPendingIRQ(EncoderB_INT_IRQN);
	NVIC_EnableIRQ(EncoderA_INT_IRQN);
    NVIC_EnableIRQ(EncoderB_INT_IRQN);
}

void timer_init(void)
{
    //定时器中断
	NVIC_ClearPendingIRQ(TIME_End_INST_INT_IRQN);
	NVIC_EnableIRQ(TIME_End_INST_INT_IRQN);
	NVIC_ClearPendingIRQ(Pid_Time_INST_INT_IRQN);
	NVIC_EnableIRQ(Pid_Time_INST_INT_IRQN);
	NVIC_ClearPendingIRQ(Huidu_Time_INST_INT_IRQN);
	NVIC_EnableIRQ(Huidu_Time_INST_INT_IRQN);
}

/**/
/********************************************
函数功能：中断读取编码器
参数：无
返回值：无
********************************************/
void GROUP1_IRQHandler(void)
{
    /* 合并GPIO状态读取 */
    const uint32_t encoderA_pins = EncoderA_PIN1_PIN | EncoderA_PIN2_PIN;
    const uint32_t encoderB_pins = EncoderB_PIN3_PIN | EncoderB_PIN4_PIN;
    
    // 原子化操作：单次读取所有相关引脚状态
    uint32_t gpioA = DL_GPIO_getEnabledInterruptStatus(EncoderA_PORT, encoderA_pins);
    uint32_t gpioB = DL_GPIO_getEnabledInterruptStatus(EncoderB_PORT, encoderB_pins);

    /* 编码器A处理（优化为位操作+状态合并） */
    if(gpioA) {
        // 同时读取两个引脚电平（减少IO操作）
        bool pin1State = DL_GPIO_readPins(EncoderA_PORT, EncoderA_PIN1_PIN);
        bool pin2State = DL_GPIO_readPins(EncoderA_PORT, EncoderA_PIN2_PIN);

        // 正交解码逻辑优化
        switch(gpioA) {
            case EncoderA_PIN1_PIN:
                Encoder.temp_countl += (pin2State ? -1 : 1);
                break;
            case EncoderA_PIN2_PIN:
                Encoder.temp_countl += (pin1State ? 1 : -1);
                break;
            default: // 处理意外情况
                break;
        }
    }

    /* 编码器B处理（相同优化模式） */
    if(gpioB) {
        bool pin3State = DL_GPIO_readPins(EncoderB_PORT, EncoderB_PIN3_PIN);
        bool pin4State = DL_GPIO_readPins(EncoderB_PORT, EncoderB_PIN4_PIN);

        switch(gpioB) {
            case EncoderB_PIN4_PIN:
                Encoder.temp_countr += (pin3State ? 1 : -1);
                break;
            case EncoderB_PIN3_PIN:
                Encoder.temp_countr += (pin4State ? -1 : 1);
                break;
            default:
                break;
        }
    }

    /* 统一清除中断标志 */
    DL_GPIO_clearInterruptStatus(EncoderA_PORT, encoderA_pins);
    DL_GPIO_clearInterruptStatus(EncoderB_PORT, encoderB_pins);
}


void TIME_End_INST_IRQHandler(void)
{
    if( DL_TimerG_getPendingInterrupt(TIME_End_INST) == DL_TIMER_IIDX_ZERO )
	{
        Encoder.countr = Encoder.temp_countr;
        Encoder.temp_countr = 0 ;
        Encoder.countl = Encoder.temp_countl;
        Encoder.temp_countl = 0 ;
				encoder_count+=Encoder.countl;//calculate distance
				encoder_count+=Encoder.countr;//calculate distance
    }
	
}

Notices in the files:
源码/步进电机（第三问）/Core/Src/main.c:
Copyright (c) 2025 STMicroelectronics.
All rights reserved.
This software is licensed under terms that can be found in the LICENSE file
